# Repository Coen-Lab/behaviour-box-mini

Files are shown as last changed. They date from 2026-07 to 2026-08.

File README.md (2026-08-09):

# Behaviour Box
A deliberately simple, open-source box for recording mouse locomotion, built as a first step
towards scalable behavioural phenotyping. About **£1095** a box, six printed parts, half an hour to
assemble.

<p align="center">
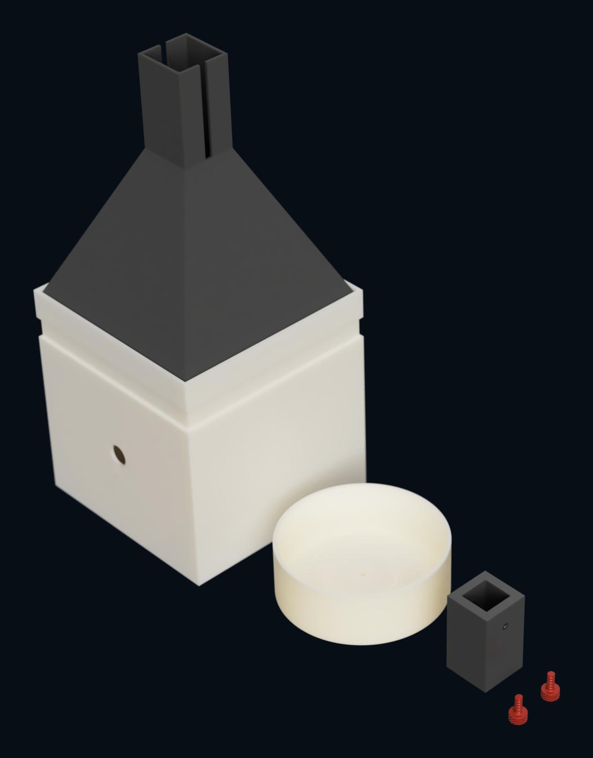
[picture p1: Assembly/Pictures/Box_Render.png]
Render of the six printed parts: box body with the lid fitted, running wheel, camera holder and two screws

</p>

## Overview

Every part is either printed or bought off the shelf, nothing needs machining, and the printed
parts need no supports. Simplicity is the point: a box that is quick to replicate, cheap enough to
run in parallel, and hard to set up wrongly.

The box pairs video capture with rotary-encoder wheel tracking, using Harp for synchronised
timestamping and Bonsai for control and acquisition. The aim is to pre-screen animals before
downstream experiments, so behavioural differences show up early — improving experimental
efficiency and reducing the number of animals needed later.

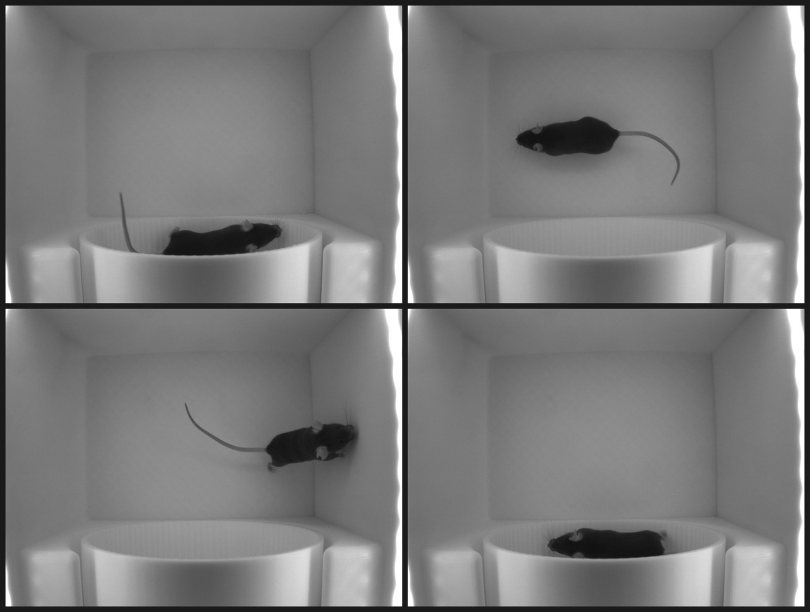
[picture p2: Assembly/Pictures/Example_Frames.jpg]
Four frames from one recording: a black mouse in the arena and on the running wheel, lit by the infrared strip


*Four frames from a single session. The wheel is against the far wall; the mouse is tracked by
centroid in both the arena and the wheel, under 850 nm light it cannot see.*

## What you get

- **Video** — continuous capture at 50 Hz for observation and offline analysis
- **Wheel locomotion** — cumulative running distance from a 1024 ppr encoder, sampled per frame
- **One clock** — the Harp board triggers the camera and timestamps the encoder, so the two streams
  share a time base rather than being aligned afterwards

## Bill of materials

| # | Part | Qty | Supplier | Cost (£) | Notes |
|---|---|-----|---|---|---|
| 1 | [PLA filament](https://uk.store.bambulab.com/products/pla-basic-filament) | 2 | Bambu Lab | 36 | 18 each |
| 2 | [FLIR Blackfly S camera](https://www.digikey.co.uk/en/products/detail/flir-integrated-imaging-solutions-inc/BFS-U3-16S2M-CS/16528335) | 1 | DigiKey | 277 | BFS-U3-16S2M-CS |
| 3 | [Rotary encoder](https://www.aliexpress.com/item/1005005665235932.html) | 1 | AliExpress | 18 | **1024 ppr** version, see notes |
| 4 | [Harp Behaviour Board](https://open-ephys.org/harp/oeps-1216) | 1 | Open Ephys | 415 | Listed at €510 |
| 5 | [Locking USB 3.0 Micro-B cable](https://www.amazon.co.uk/dp/B0BYDYKB75) | 1 | Amazon | 18 | 5 m, straight connector |
| 6 | [GPIO cable](https://www.digikey.co.uk/en/products/detail/flir-integrated-imaging-solutions-inc/ACC-01-3010/16528421) | 1 | DigiKey | 33 | Camera trigger. FLIR ACC-01-3010, Hirose HR10 6-pin, 4.5 m |
| 7 | [Varifocal lens, 2.8-12 mm, CS mount](https://www.aliexpress.com/item/1005006136279769.html) | 1 | AliExpress | 12.49 | Manual zoom and focus, no IR filter |
| 8 | [IR LED strip, 850 nm, 12 V](https://www.aliexpress.com/item/1005009046927133.html) | 2 m | AliExpress | 26 | Cut to length. Three walls need about 0.6 m |
| 9 | [Mini PC, e.g. GEEKOM Air12](https://www.amazon.co.uk/dp/B0CPLNDHZ5) | 1 | Amazon | 240 | Meets the minimum specification below |
| 10 | [M3 hex screw set, 6-14 mm](https://www.aliexpress.com/item/1005008068815080.html) | 1 | AliExpress | 9 | May be optional, see notes |
| 11 | [RJ45 breakout](https://www.aliexpress.com/item/1005009050450182.html) | 1 | AliExpress | 2 | Gets the encoder wires into Port 2 |
| 12 | [Screw terminal blocks, 5-way](https://www.aliexpress.com/item/1005007993530438.html) | 1 | AliExpress | 6.25 | Pack of 10. One terminates the encoder |
| 13 | [12 V power supply](https://www.aliexpress.com/item/4000056698173.html) | 1 | AliExpress | 2.45 | For the IR LED strip |

Approximate total: £1095

**Notes**

- **Encoder resolution** — row 3 is sold in several resolutions off the same listing, and they are
  indistinguishable in the product photographs. Choose **1024 ppr**: the workflow ships with
  `CountsPerRev` set to 4096, which is 1024 quadrature-decoded x4. Fit a different resolution
  without changing that value and `WheelDistance` is wrong in every recording, with nothing in the
  data to say so. See [Software](Software/).
- **Rotary encoder alternative** — [Omron E6B2-CWZ6C 360P/R 0.5M](https://uk.rs-online.com/web/p/motion-control-sensors/2158863),
  RS stock 215-8863, £216.14 exc VAT. Same NPN open-collector output and 6 mm shaft, but 360 ppr
  rather than 1024, and about twelve times the price. Worth it only if you need a warranted part.
  It needs `CountsPerRev` changed to 1440.
- **Screws** — Omron encoders ship with an E69-2 bracket and three M3 x 10 Phillips screws, which may
  cover the encoder mount on their own. The assembly guide calls for three M3 x 8 mm hex screws and a
  2 mm Allen key, so check what arrives before ordering row 10.

### Computer minimum specification

One machine per box runs Bonsai and writes the video. The GEEKOM Air12 in row 9 is the cheapest
unit we have found that clears the bar, so its specification is the floor:

| | Minimum |
|---|---|
| CPU | 4-core x86, Intel N-series or PT7505 class |
| RAM | 16 GB |
| Storage | 512 GB NVMe SSD |
| USB | One USB 3.2 Gen 1 Type-A port dedicated to the camera |
| OS | Windows 11, for Bonsai and the Spinnaker SDK |

Two things to watch:

- **No PCIe slot** on a mini PC, so the camera runs from a built-in port rather than an expansion card.
- **Storage** — compressed video runs at roughly 4-16 GB per hour, so 512 GB holds days rather than
  weeks. Uncompressed it would fill in under two hours, at the shipped 1440 x 1080 and 50 Hz. Binning
  2 quarters all of these figures, at half the resolution in each direction.

## Build guide

Four steps, a couple of days of printing and half an hour of assembly.

| Step | What it involves | Guide |
|---|---|---|
| 1. Print | Six parts from five STLs in [`Assembly/Parts`](Assembly/Parts/): arena, lid, camera holder, wheel, and the thumb screw twice. 15% infill, no supports, three plates on a standard Bambu Lab printer or equivalent. | [Assembly](Assembly/) |
| 2. Assemble | Mount the encoder, fit the wheel to its D-shaft, clamp the camera in its holder with the lens, and line three walls with the IR strip. 20-30 minutes. | [Assembly](Assembly/) |
| 3. Wire | Camera to computer over locking USB, GPIO trigger and encoder to the Harp board. | [Wiring](Assembly/Wiring.md) |
| 4. Software | Install the Spinnaker SDK, run `Setup.cmd`, open the workflow. | [Software](Software/) |

### Installing the software

Order matters: Bonsai cannot see the camera without the Spinnaker driver already in place.

1. **Spinnaker SDK 4.2.0.83** — download from
   [Teledyne Vision Solutions](https://www.teledynevisionsolutions.com/support/support-center/software-firmware-downloads/iis/spinnaker-sdk-download/spinnaker-sdk--download-files/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).
   The version must match exactly; the download page defaults to the latest, so choose deliberately.
   An account is required, so this step cannot be scripted.
2. **Bonsai** — run `Software\Setup.cmd`. It downloads Bonsai and
   restores every package from `Bonsai.config`, and warns if Spinnaker is missing or the wrong
   version. Nothing else needs installing by hand.
3. **Open the workflow** — start Bonsai, then **File → Open** →
   `Behaviour_Box.bonsai`. Do not launch the workflow file directly: this project relies on
   compatibility patches.

Full detail, including camera settings, is in [Software](Software/).

## How to run the workflow

Configure the camera and experiment settings first — see [Software](Software/). Then:

1. Clean the box with **70% ethanol** or another disinfectant, and wipe it completely dry.

2. Connect the hardware, with the box still empty:
   - 12 V power supply to the Harp Behaviour Board
   - Rotary encoder to the Harp Behaviour Board (**Port 2**)
   - IR LED strip power supply
   - Camera USB cable to the computer
   - Camera GPIO trigger cable to the Harp Behaviour Board

3. Open the Bonsai workflow and check the **live camera preview** is updating.

4. Place the mouse in the box.

5. Fit the lid with the camera attached.

6. Minimise external light — turn the room lights off, or cover the box with black fabric (**recommended**).

7. Set the save directory, camera serial number, subject ID, session ID and trial length, then click
   **Start**.

8. Recording stops automatically at the trial length, saving a video and a CSV of the behavioural data.

9. Return the mouse to its home cage.

10. Clean the box before the next recording, checking the corners carefully — faeces are easy to miss.

## Troubleshooting

- **No live camera preview** — check the locking USB 3.0 cable is connected, the correct Spinnaker
  SDK version is installed, and the camera serial number matches the connected device.
- **Rotary encoder not responding** — check the RJ45 connection to the Harp Behaviour Board and that
  the encoder is on the correct input pins.
- **Preview or CSV window missing** — reopen them manually, as below.

### Reopening the camera preview

1. Right-click the **Logging** node and select **Show Default Editor...**
2. In the editor window, right-click the **LogVideo** node and select **Show Default Editor...**
3. Right-click the **VideoWriter** node and select:
   - **Show Visualizer**
   - **Bonsai.Vision.Design.IplImageVisualizer**

### Reopening the CSV output

1. Right-click the **CsvWriter** node.
2. Select:
   - **Show Visualizer**
   - **Bonsai.Design.ObjectTextVisualizer**

> **Tip**
>
> Do not close these visualizer windows by hand. Bonsai closes them when the workflow stops, and
> reopens them on the next run.

## License

Released under the [MIT License](LICENSE), which covers the printed design as well as the workflow
and the documentation.

The five UclOpen packages in `local_packages/` are redistributed under the BSD 3-Clause License, and
everything `Setup.cmd` downloads stays under its own terms. See
[THIRD-PARTY-NOTICES.md](THIRD-PARTY-NOTICES.md).

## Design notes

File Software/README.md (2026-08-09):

# Software

Two components:

- **Spinnaker SDK (SpinView)** — camera driver and configuration
- **Bonsai** — acquisition, encoder recording, trigger control and data saving

Install them in that order: Bonsai cannot see the camera without the Spinnaker driver.

---

## Spinnaker SDK (SpinView)

Spinnaker is Teledyne FLIR's official package. It provides the camera driver and lets you configure
image size, exposure time, gain, frame rate and trigger mode.

Download it from
[Teledyne Vision Solutions](https://www.teledynevisionsolutions.com/support/support-center/software-firmware-downloads/iis/spinnaker-sdk-download/spinnaker-sdk--download-files/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).
An account is needed, so this step cannot be scripted and must be done by hand.

> **Important**
>
> Bonsai works only with Spinnaker SDK **4.2.0.83**. Pick the version deliberately: the download page
> defaults to the latest.
>
> This is upstream's requirement, not a local quirk. `Bonsai.Spinnaker 0.9.1` states it in its package
> description and ships a matching `SpinnakerNET_v140.dll` at exactly 4.2.0.83. The package provides
> the managed wrapper while the SDK provides the native runtime, and the two are version-locked, so a
> mismatch fails at interop and shows up as the camera simply not appearing.

---

## Bonsai

Run [`Setup.cmd`](Setup.cmd) once. It downloads Bonsai and restores
the packages listed in `Bonsai.config` from nuget.org and `local_packages/`, so nothing else needs
installing by hand.

Then, because of compatibility patches in this project, open the workflow manually rather than
launching it directly:

1. Open **Bonsai**.
2. Select **File → Open**.
3. Open **`Behaviour_Box.bonsai`**.

With the workflow loaded, click the blank workspace to bring up the experiment settings in the
**Properties** panel on the right. Set before each recording:

- Save directory
- 8-digit camera serial number
- Session ID
- Subject ID
- Trial length (minutes)

The same panel also carries the settings you change rarely rather than per recording: `PortName`,
`ExposureTime`, `Gain`, `Binning`, `TrackingThreshold`, `CountsPerRev` and `WheelDiameterMm`. None
of them require opening a group.

Recording stops automatically at the trial length, saving a **CSV** of behavioural data and a
**video**.

### Serial port

One thing is set once per machine rather than per recording. The Harp Behaviour Board appears as a
COM port, and the workflow ships pointing at **COM3**, which will be wrong on most computers. Find
the board in Device Manager under **Ports (COM & LPT)**, then set **PortName** in the same
**Properties** panel.

Get this wrong and the workflow fails on startup without saying why.

### Data output

Each recording gets its own folder, built from the settings above:

```
<save directory>\sub-<SubjectId>\ses-<SessionId>_date-<yyyy-MM-ddTHH-mm-ss>
```

The date is the UTC time at which the workflow started, so a late-evening session in British
Summer Time files under the following day. The folder holds `LogData.csv` and
`VideoData_Camera.avi`, the video written as MPEG-4 Part 2 in an AVI container.

The CSV has one row per camera frame, with a header:

| Column | Meaning |
|---|---|
| `Seconds` | Harp clock time of the frame trigger, in seconds |
| `Timestamp` | Camera chunk timestamp |
| `FrameID` | Camera frame counter |
| `ExposureTime` | Exposure of that frame, from the camera chunk |
| `MouseLocation.X` | Mouse centroid, pixels from the left edge of the image |
| `MouseLocation.Y` | Mouse centroid, pixels from the top edge of the image |
| `WheelDistance` | Cumulative distance run since the recording started, in cm |

The centroid is a `Point2f`, which Bonsai's CsvWriter splits into the two dotted columns above
rather than one combined field, so the file has seven columns. The origin is the top-left pixel and
Y increases downwards, following OpenCV.

`MouseLocation.X` and `MouseLocation.Y` are `NaN` on any frame where tracking found nothing. The
threshold segments pixels darker than 35, so an empty box gives `NaN` on every row, which is the
correct answer rather than a fault. Occasional `NaN` mid-session means the animal was momentarily
lost; a session that is entirely `NaN` with an animal present means the threshold needs raising for
the current lighting.

`Seconds` is the Harp board's own record of when it fired the trigger, matched to the frame by
arrival order rather than by any shared identifier. That holds as long as every trigger produces a
frame. If one ever does not, each frame after it takes the timestamp of the frame before, and
nothing in the file announces it. To check a session, compare the camera's own `Timestamp` against
`Seconds`: the offset between the two clocks should be flat, and a step of one frame period means
the pairing has slipped.

Expect the **first row to be wrong** and discard it. Logging starts against a camera that is already
being triggered, so the first frame is paired with a trigger event that arrived before it, and its
`Seconds` can be most of a second early. `FrameID` stays contiguous across it, confirming no frame
was lost. From the second row on, the offset locks and stays flat.

Acquisition constants, all set in the workflow:

| | Value |
|---|---|
| Frame rate | 50 Hz, camera hardware-triggered by the Harp board |
| Exposure | 10 ms |
| Gain | 5 dB |
| Binning | 1, so the full 1440 x 1080 sensor is recorded |
| Encoder counts per revolution | 4096 (1024 ppr, quadrature decoded x4) |
| Wheel diameter | 150 mm, so a circumference of 47.12 cm |
| Distance per encoder count | 0.0115 cm |

`WheelDistance` accumulates the per-sample encoder difference, with 16-bit counter wraparound
corrected, so it increases monotonically while the animal runs forwards and is not reset within a
session. Change `CountsPerRev` or `WheelDiameterMm` in the top-level **Properties** panel if you use
a different encoder or wheel, or the distances will be silently wrong.

The board is put in **Position** mode, so the encoder register reports an absolute count that the
workflow differences, unwraps and re-accumulates. UclOpen's own `RunningWheel` uses **Displacement**
mode instead, and that is deliberately not copied here: it reports differences already, so the same
chain would difference them twice and the distances would be meaningless.

---

## Camera settings

The workflow ships with recommended settings and should not need changing. If it does:

### Exposure time, gain and binning

Click the blank workspace at the top level. `ExposureTime`, `Gain` and `Binning` sit in the same
**Properties** panel as the per-recording settings, so there is no need to open the `metadata` group.

The order to tune them in is exposure first, then gain, then binning:

- **Exposure** buys image quality for free, so make it as long as the frame period allows. At 50 Hz
  a frame lasts 20 ms, and the shipped 10 ms leaves half the period spare, so this is the first
  thing to raise if the image is too dark. Going over the frame period does not slow the camera down
  gracefully: it drops triggers, and because frames are paired with trigger events in order, a
  dropped one shifts every timestamp after it.
- **Gain** amplifies noise along with signal, so keep it as low as the image allows. Reach for it
  only once exposure is maxed out and the picture is still too dark, and prefer adding IR
  illumination instead.
- **Binning** is the file-size control. It sums neighbouring pixels, so it brightens the image and
  cuts noise, at the cost of resolution. The box ships at binning 1, recording the full 1440 x 1080
  sensor. Binning 2 gives 720 x 540, quarters the data rate and brightens the image about fourfold,
  which is worth having if storage or the encoder become the limit.

### A cropped image

The workflow sets binning but not the region of interest, because `TriggeredSpinnaker` does not
expose one. `OffsetX`, `OffsetY`, `Width` and `Height` are therefore whatever is stored on the
camera, and Bonsai accepts them. A camera left with a small region records a cropped frame, and the
CSV looks identical either way.

The trap is that changing binning in SpinView does not re-expand the region. It stays at its old
pixel values, so the image crops rather than rescaling. To reset it, with Bonsai closed:

1. Set `OffsetX` and `OffsetY` to 0. The offsets must come down before the size can go up.
2. Set `Width` and `Height` to their maxima. At binning 1 that is 1440 x 1080.

To make it survive a power cycle, save it to the camera: set `UserSetSelector` to UserSet1, execute
`UserSetSave`, then set `UserSetDefault` to UserSet1. Otherwise the camera reverts to its stored
default whenever it loses power.

### Frame rate

The camera is hardware-triggered, so its frame rate is set by the Harp board rather than by the
camera. Changing it means changing three things together, or the recordings go wrong quietly:

1. **Trigger0Frequency** on the `CameraTriggerController` node, inside **metadata** then
   **BehaviorBoards**. This is the one that actually sets the rate.
2. The **frames-per-second multiplier** in the **logging** group, which turns the trial length in
   minutes into a frame count. If it disagrees with the trigger, recordings stop at the wrong
   length.
3. **FrameRate** on the `VideoWriter` node, inside **logging** then **LogVideo**. This only labels
   the AVI, but if it is wrong the video plays back at the wrong speed.

Check the exposure still fits inside the new frame period.

## Mouse centroid tracking

Position is estimated by **centroid tracking**. Compared with pose estimation or segmentation it is
computationally light, robust, and accurate enough for locomotion, which suits a standardised
screening platform.

The centroid is in pixels, and nothing in the recording converts it to distance. The arena floor is
a 200 mm square, which gets you an approximate scale, but for anything quantitative calibrate your
own box: put a ruler or a printed grid on the floor, record a frame, and measure the millimetres per
pixel. The lens is a varifocal focused by hand, so the scale belongs to your box and changes the
moment anyone touches the zoom ring.

Nothing is classified online: if you need to know whether the animal was on the wheel or in the
arena, test the logged coordinates against a wheel region offline. Doing it after the fact means one
region definition applied identically to every session, rather than one drawn by hand per rig.

> **Note**
>
> The hardware and default parameters are optimised for **black mice**. For **white or light-coloured
> mice**, either:
>
> - Print the box in a darker colour to increase contrast, or
> - Adjust `TrackingThreshold` in the top-level **Properties** panel. It ships at 35 and segments
>   pixels *darker* than that value, so a light animal on a light floor needs the box inverted in
>   colour rather than the threshold nudged.

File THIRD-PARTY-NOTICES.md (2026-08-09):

# Third-party notices

Everything in this repository is covered by the [MIT License](LICENSE) except the components listed
below, which are redistributed under their own terms.

## UclOpen packages

`Software/Behaviour_Box/local_packages/` contains five NuGet packages, redistributed as
binaries because they are not published on nuget.org and the workflow will not restore without them:

- `UclOpen.Core.0.0.0-sandbox`
- `UclOpen.Devices.0.0.0-sandbox`
- `UclOpen.Logging.0.0.0-sandbox`
- `UclOpen.Video.0.0.0-sandbox`
- `UclOpen.Vision.0.0.0-sandbox`

They come from [ucl-open/ucl-open](https://github.com/ucl-open/ucl-open) at commit
`27892d3ee53b8297eeede92571668fed8c425248`, and each carries the licence text below in its own
`LICENSE` file.

```
BSD 3-Clause License

Copyright 2026 (c) University College London and Contributors

Redistribution and use in source and binary forms, with or without
modification, are permitted provided that the following conditions are met:

1. Redistributions of source code must retain the above copyright notice, this
   list of conditions and the following disclaimer.

2. Redistributions in binary form must reproduce the above copyright notice,
   this list of conditions and the following disclaimer in the documentation
   and/or other materials provided with the distribution.

3. Neither the name of the copyright holder nor the names of its
   contributors may be used to endorse or promote products derived from
   this software without specific prior written permission.

THIS SOFTWARE IS PROVIDED BY THE COPYRIGHT HOLDERS AND CONTRIBUTORS "AS IS"
AND ANY EXPRESS OR IMPLIED WARRANTIES, INCLUDING, BUT NOT LIMITED TO, THE
IMPLIED WARRANTIES OF MERCHANTABILITY AND FITNESS FOR A PARTICULAR PURPOSE ARE
DISCLAIMED. IN NO EVENT SHALL THE COPYRIGHT HOLDER OR CONTRIBUTORS BE LIABLE
FOR ANY DIRECT, INDIRECT, INCIDENTAL, SPECIAL, EXEMPLARY, OR CONSEQUENTIAL
DAMAGES (INCLUDING, BUT NOT LIMITED TO, PROCUREMENT OF SUBSTITUTE GOODS OR
SERVICES; LOSS OF USE, DATA, OR PROFITS; OR BUSINESS INTERRUPTION) HOWEVER
CAUSED AND ON ANY THEORY OF LIABILITY, WHETHER IN CONTRACT, STRICT LIABILITY,
OR TORT (INCLUDING NEGLIGENCE OR OTHERWISE) ARISING IN ANY WAY OUT OF THE USE
OF THIS SOFTWARE, EVEN IF ADVISED OF THE POSSIBILITY OF SUCH DAMAGE.
```

## Not redistributed here

`Software/Setup.cmd` downloads Bonsai and restores the packages listed in `Bonsai.config` from
nuget.org at install time. None of those are stored in this repository, and each remains under its
own licence. Bonsai itself is MIT, copyright the Bonsai Foundation CIC and Contributors.

The Spinnaker SDK is installed by hand from Teledyne and is not redistributed in any form.

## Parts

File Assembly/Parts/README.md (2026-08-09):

# Printed parts

One STL per unique component. Six printed parts in total, five unique geometries: the thumb screw
is printed twice.

| File | Print | What it is |
| --- | --- | --- |
| `Arena.stl` | 1 | Box body, 207 x 207 x 220 mm |
| `LidAndSpacer.stl` | 1 | Tapered tower: closes the box and sets camera height, 199 x 199 x 240 mm |
| `CamHolder.stl` | 1 | Clamps the camera between body and lens, 46 x 46 x 80 mm |
| `Wheel.stl` | 1 | Running wheel, 157 mm diameter |
| `ThumbScrew.stl` | 2 | Both screws are the same part, 16 x 16 x 25 mm |

Exported from `Complete_Package` in Fusion. The meshes carry their assembly coordinates rather than
being centred on the origin, so parts land away from the plate when first loaded. Any slicer will
drop them to the bed and place them; nothing about the geometry needs changing.

For print settings and the build order see [../README.md](../README.md).

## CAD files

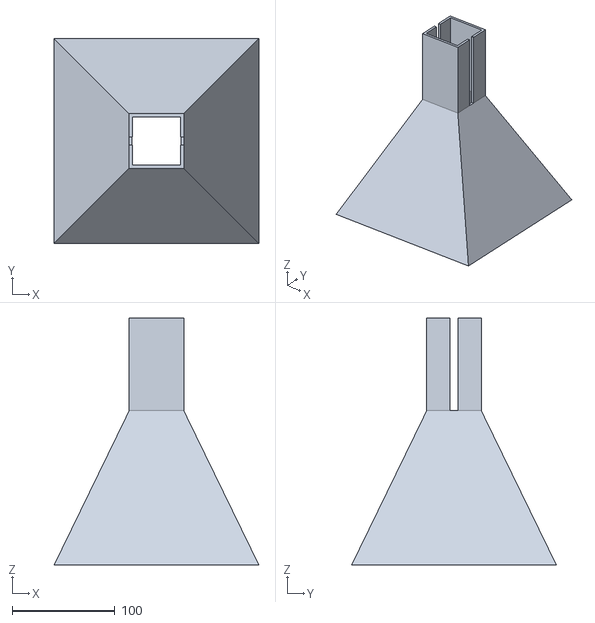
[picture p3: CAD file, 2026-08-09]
Assembly/Parts/LidAndSpacer.stl
199.0 x 199.0 x 240.0

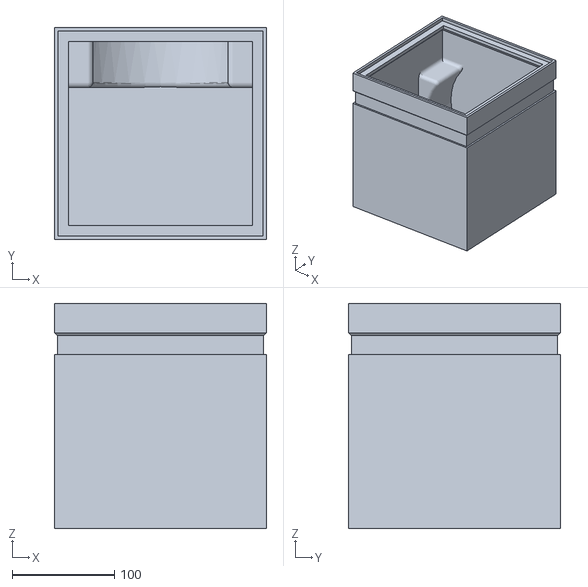
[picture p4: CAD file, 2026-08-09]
Assembly/Parts/Arena.stl
207.0 x 207.0 x 220.0

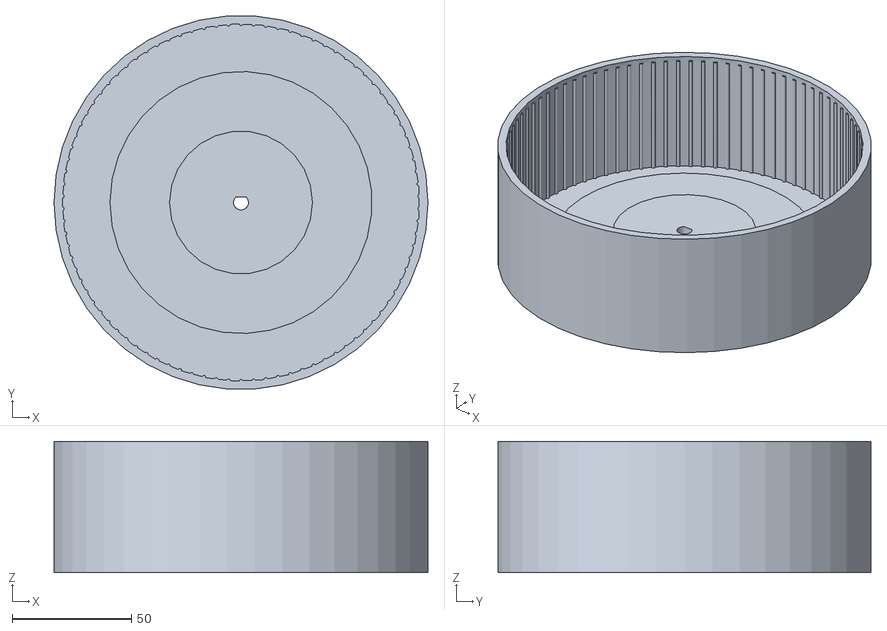
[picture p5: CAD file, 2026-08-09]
Assembly/Parts/Wheel.stl
157.0 x 156.6 x 55.0

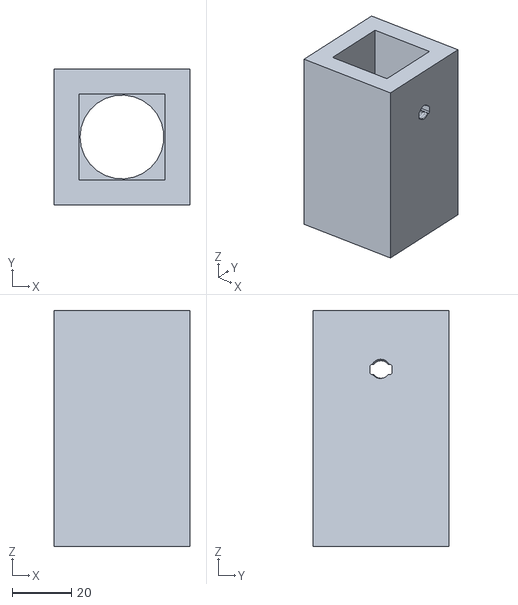
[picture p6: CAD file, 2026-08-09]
Assembly/Parts/CamHolder.stl
46.0 x 46.0 x 80.0

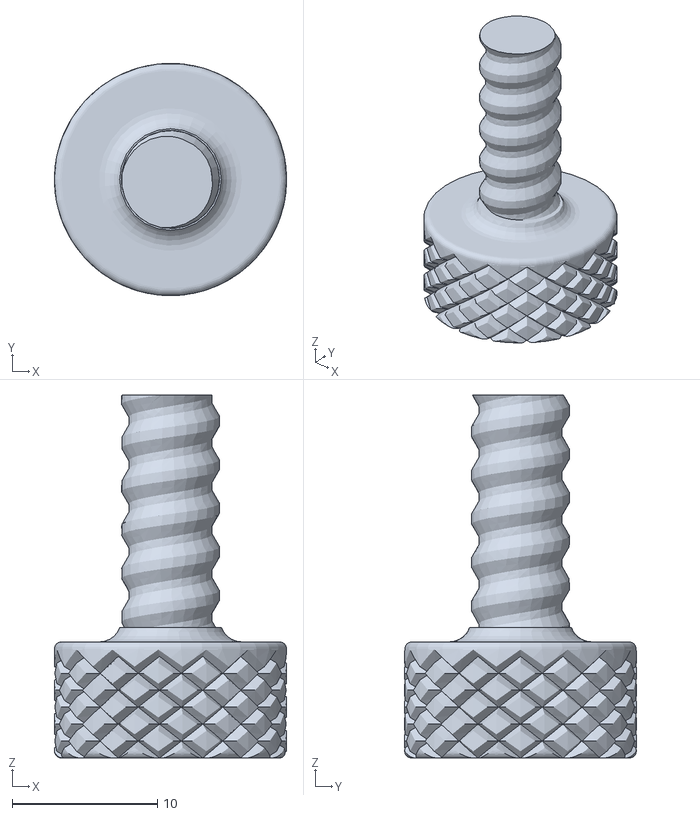
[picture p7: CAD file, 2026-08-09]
Assembly/Parts/ThumbScrew.stl
16.0 x 16.0 x 25.0

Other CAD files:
Assembly/Behaviour_Box_Complete.step
Assembly/Behaviour_Box_Complete.stl

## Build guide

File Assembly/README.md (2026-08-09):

# Assembly

Printing, assembling and wiring the box. For the parts list and prices see the
[Bill of materials](../README.md#bill-of-materials); for wiring see [Wiring](Wiring.md).

Six printed parts, from five files in [`Parts/`](Parts/):

- `Arena.stl` — the box body
- `LidAndSpacer.stl` — the tapered tower that closes the box and sets the camera height above the
  arena. It is 240 mm tall, so it doubles the assembled height to 460 mm; allow for that on the
  bench and in the printer
- `CamHolder.stl` — camera holder
- `Wheel.stl` — running wheel
- `ThumbScrew.stl` — printed twice; both screws are the same part

Everything else is bought off the shelf, as listed in the [Bill of materials](../README.md#bill-of-materials).
Assembly takes 20-30 minutes.

<p align="center">
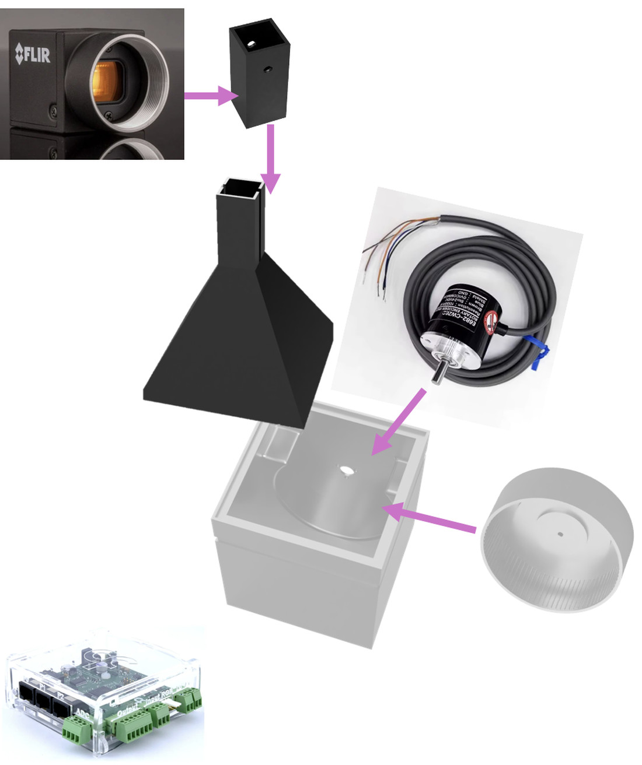
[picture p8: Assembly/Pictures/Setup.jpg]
Assembly overview: the camera slides into the camera holder, the holder into the top of the lid, the lid onto the box body; the encoder mounts through the side wall and the wheel onto its shaft; the Harp Behaviour Board sits outside
  
</p>

<p align="center"><em>How the parts go together. The Harp Behaviour Board sits outside the box; see
<a href="Wiring.md">Wiring</a>.</em></p>

## Tools required

- 2 mm Allen key, for the M3 screws
- Flat-head screwdriver

## Step 1 - Print the components

Print the five files in [`Parts/`](Parts/), taking two copies of `ThumbScrew.stl`.

| Setting | Value |
|---|---|
| Material | PLA |
| Infill | 15% |
| Supports | None needed |
| Build volume | At least 210 x 210 x 245 mm |
| Printer | Standard Bambu Lab or equivalent |

The two largest parts set the build volume: the box body is 207 mm square and 220 mm tall, and the
lid is 199 mm square and 240 mm tall. Both fit an X1 or P1 series printer, but not an A1 mini.

Each file holds one part, but the meshes keep their assembled coordinates, so they arrive spread out
and at different heights. Drop everything to the plate and arrange it yourself. They will not fit on
one plate: budget three, and closer to two or three days of printing than one.

[`Behaviour_Box_Complete.stl`](Behaviour_Box_Complete.stl) is the whole box as a single body, for
reference only — it cannot be printed. [`Behaviour_Box_Complete.step`](Behaviour_Box_Complete.step)
is the editable solid model, with each part as a separate component.

Print the box in a darker colour if you plan to record white or light-coloured mice, for contrast.

## Step 2 - Install the rotary encoder

Secure the encoder to the side wall of the box with three M3 x 8 mm screws, with the shaft facing
inwards. See [Wiring](Wiring.md) for the encoder connections.

## Step 3 - Install the running wheel

1. Turn the shaft until the flat of the D faces the matching flat inside the wheel hub.
2. Push the wheel home. It should slide on smoothly; if it needs force, the flats are not aligned.

## Step 4 - Install the camera

1. Remove the lens from the camera body.
2. Insert the camera through the camera holder from the rear.
3. Reattach the lens from the front, clamping the holder between the camera body and the lens so it
   cannot move.
4. Slide the holder into the square opening at the top of the lid and lock it with the two printed
   screws. Either screw goes in either hole.

See [Wiring](Wiring.md) for the camera power and trigger connections.

## Step 5 - Fit the infrared illumination

The 850 nm strip lights the arena for the camera without being visible to the mouse.

1. Cut about 600 mm from the 2 m reel — the interior is 200 mm square and three walls are lined.
   Cut **only on the marked cut points**, which on a 12 V strip fall every few LEDs. Cut anywhere
   else and the segment will not light.
2. Peel the backing and run the strip along **three of the four walls, leaving the wheel wall
   dark**. Three sides give even light across the floor, and keeping the strip off the wheel wall
   avoids both the encoder mount and the shadow the wheel would throw across the arena.
3. Connect the strip to its own 12 V supply, not to the Harp board.

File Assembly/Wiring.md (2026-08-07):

# Wiring

Three things connect to the system: the camera, the rotary encoder and the Harp Behaviour Board.

<p align="center">
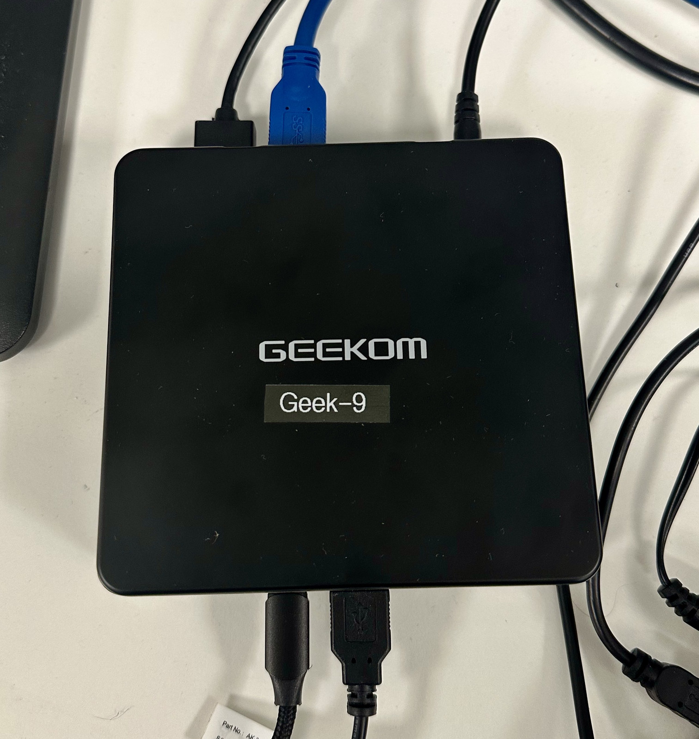
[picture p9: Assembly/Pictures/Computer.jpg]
The mini PC, with the camera USB cable and the monitor and power leads plugged in
  
</p>

---

## Camera

The camera needs two connections:

- **Locking USB 3.0 Micro-B cable** — straight to the computer, for image acquisition.
- **GPIO trigger cable** — to the **Output** port of the Harp Behaviour Board, for hardware triggering.

For the **FLIR Blackfly S (BFS-U3-16S2M-CS)** in the bill of materials:

| Camera wire | Connect to |
|---|---|
| Blue (Opto GND) | GND |
| Black (Opto In) | Trigger |

<p align="center">
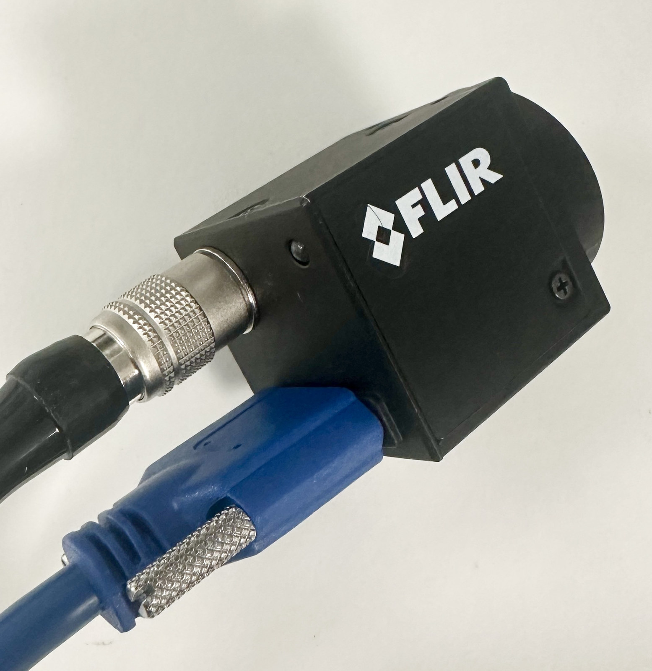
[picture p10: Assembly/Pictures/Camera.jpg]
Camera connections
  
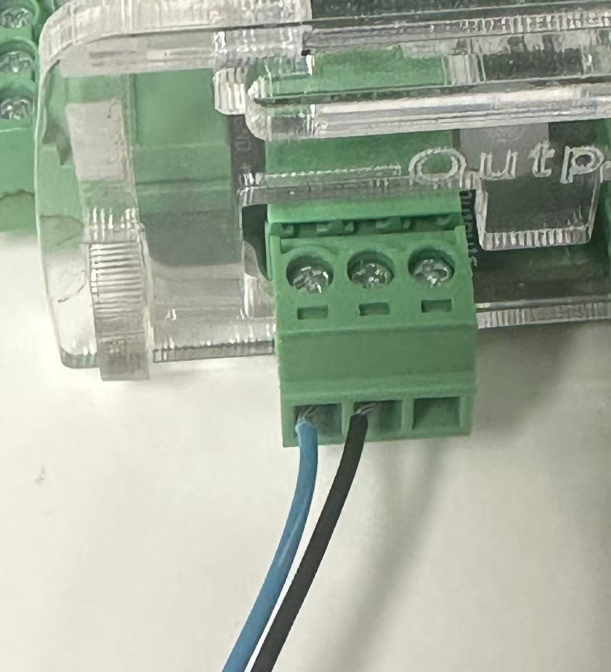
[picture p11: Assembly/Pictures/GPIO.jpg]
GPIO trigger wiring
  
</p>

Camera configuration is covered in [Software](../Software/).

---

## Rotary encoder

The encoder connects to the Harp Behaviour Board over RJ45, on **Port 2**. This is not a preference:
Port 2 is the only one of the three ports wired to the board's quadrature counter, and the workflow
enables it by name. To simplify assembly and replacement, terminate the encoder wires in an **8-way
screw terminal block** first.

The encoder has five wires, four of which are used:

| Encoder wire | Harp pin |
|---|---|
| Black (Channel A) | DI (Input A) |
| White (Channel B) | DIO (Input B) |
| Orange — *not used* | Pin 3 |
| Brown (+5 V) | Pin 4 |
| Blue (GND) | Pin 5 |

The bare braid is the cable shield, not one of the five wires.

<p align="center">
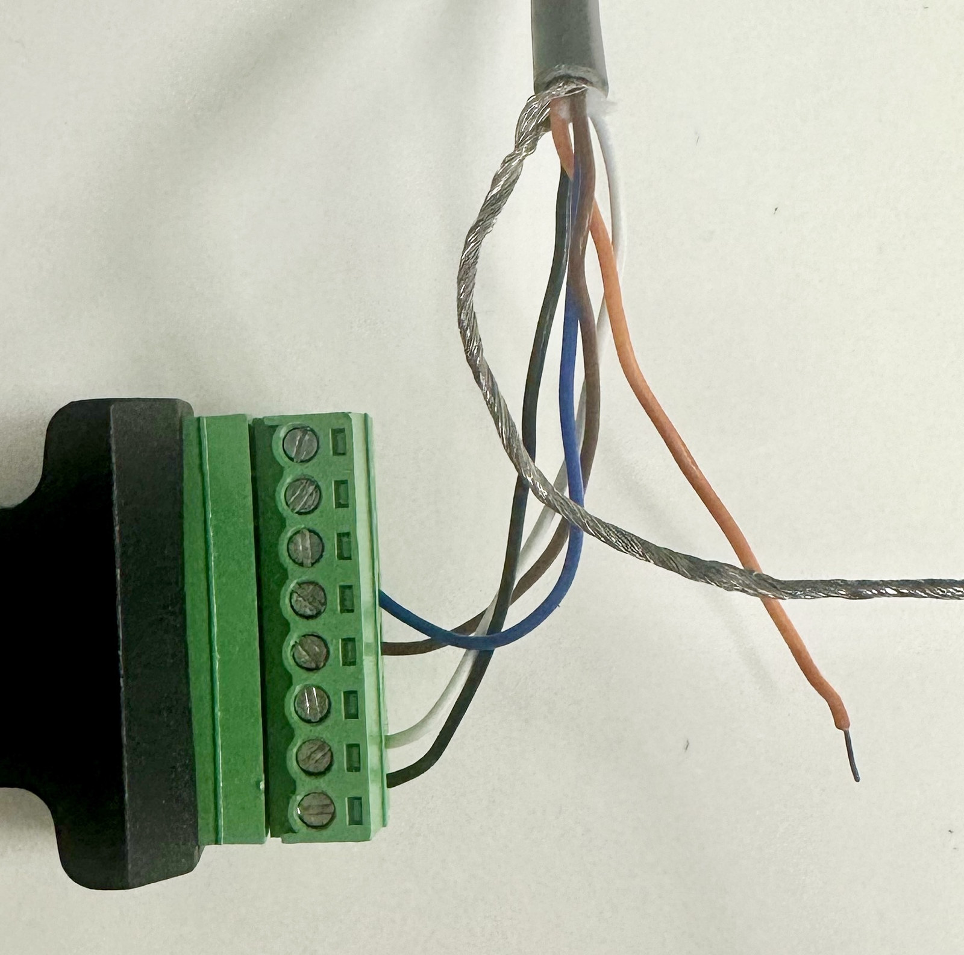
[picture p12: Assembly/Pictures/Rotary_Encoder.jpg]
Rotary encoder wiring
  
</p>

---

## Harp Behaviour Board

The board is the central interface between camera, encoder and computer. It needs:

- USB to the computer
- 12 V DC power in
- GPIO output to the camera trigger cable
- RJ45 to the rotary encoder (**Port 2**, the only port with a quadrature counter)

<p align="center">
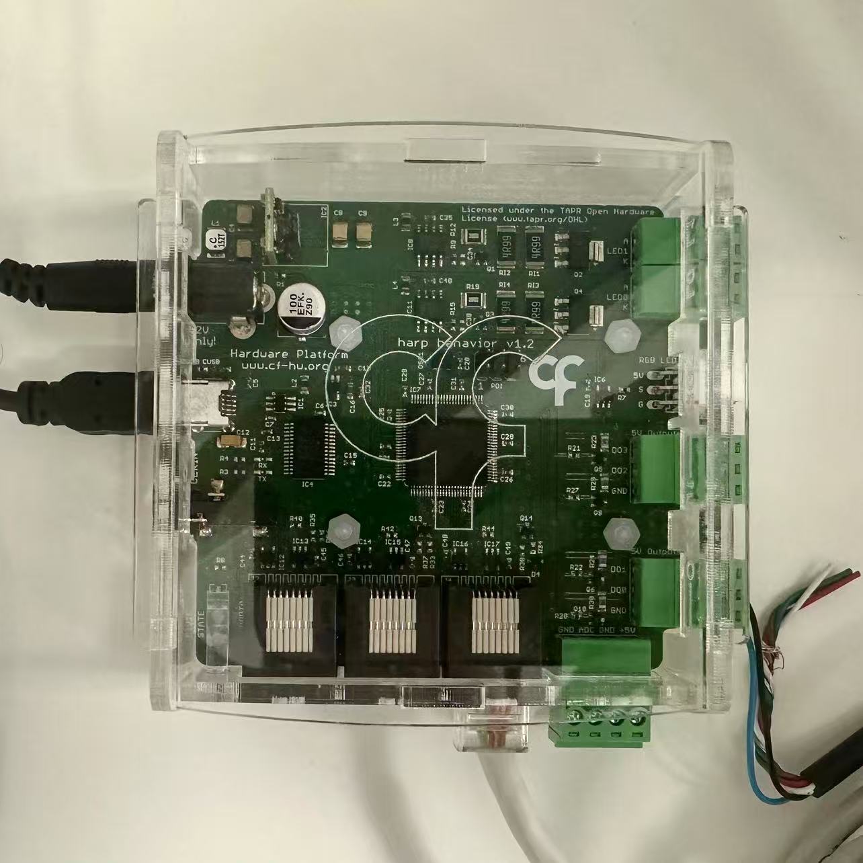
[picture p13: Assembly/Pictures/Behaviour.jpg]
Harp Behaviour Board connections
  
</p>

With the hardware connected, go to [Software](../Software/) for device configuration and
acquisition.

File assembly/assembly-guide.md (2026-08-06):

# Assembly Guide

The box is four 3D-printed PLA parts:

- Behaviour box body
- Lid
- Camera holder
- Running wheel

Everything else is bought off the shelf, as listed in the [Bill of Materials](../README.md#bill-of-materials).
Assembly takes 20-30 minutes.

<p align="center">
  Assembled behaviour box
</p>

## Tools Required

- 2 mm Allen key, for the M3 screws
- Flat-head screwdriver

## Step 1 - Print the components

Print the four PLA parts. No supports are needed; they print straight off a standard Bambu Lab
printer or equivalent, at 15% infill.

## Step 2 - Install the rotary encoder

Secure the encoder to the side wall of the box with three M3 x 8 mm screws, with the shaft facing
inwards. See [wiring](wiring.md) for the encoder connections.

## Step 3 - Install the running wheel

Slide the wheel onto the encoder shaft. The hub is designed to mate with the D-shaped shaft, so
align the flat of the shaft with the matching flat inside the hub before pushing the wheel home. It
should slide on smoothly, without excessive force.

## Step 4 - Install the camera

1. Remove the lens from the camera body.
2. Insert the camera through the camera holder from the rear.
3. Reattach the lens from the front, clamping the holder between the camera body and the lens so it
   cannot move.

See [wiring](wiring.md) for the camera power and trigger connections.

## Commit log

2026-07-24 Revise assembly guide and update step numbering
    Updated assembly guide to reflect changes in step numbering and removed unnecessary text.
2026-07-24 Update build guide for printing and assembly
    Consolidate print and assembly steps in the build guide.
2026-07-27 Improve image alignment in wiring.md
    Updated image formatting for better alignment in wiring documentation.
2026-07-27 Revise wiring.md with updated connections and images
    Updated wiring instructions and added images for clarity.
2026-07-27 Fix formatting issues in wiring documentation
2026-07-27 Update assembly guide with material and tool details
    Added note about printed parts being designed for PLA and updated tools required section.
2026-07-27 Adjust image width in assembly guide
    Increased the image width in the assembly guide.
2026-08-06 Add lens, IR strip, computer and screws to the BOM
    Link the rows that map to parts already in RegularOrders.xlsx and
    AliExpressOrders.xlsx, so suppliers and prices match what the lab pays.
    The GPIO cable is the FLIR ACC-01-3010 and the camera comes from Digikey
    at the price we last paid.
    Add four rows the BOM was missing: the CS-mount varifocal lens, the
    850 nm IR strip the run instructions already assume, the mini PC, and the
    M3 screw set. Give the computer a minimum specification, since the
    workflow depends on one but never said what it needs.
    Add a collage of example frames and an exploded render of the printed
    parts.
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2026-08-06 Use the exploded render as the header image
    Replaces the hosted model screenshot. The render lives in the repo rather
    than in GitHub attachment storage, and it shows every printed part rather
    than the assembled box alone. Drops the duplicate copy from the build
    guide.
2026-08-06 Rebuild the header render from the green-screen export
    Keying against grey was never going to work: the box's shaded left face
    sits 13 counts from the background, so removing background-coloured edge
    pixels also removed part of the model, leaving a ragged silhouette.
    Green shares no ground with the model's white, black and red, so the
    matte comes from green dominance instead of colour distance. No opaque
    green-tinted pixels survive, and no erosion is needed.
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2026-08-06 Use the solid-background render and tighten the README
    Swap in the render exported against a solid dark background, replacing
    the keyed transparent version.
    Convert the features list to bullets, cut repetition from the overview
    and run-through, and lead on the design being simple to build. Fix the
    software link, which pointed at assembly/ rather than Softwares/.
    Note what the M3 screws are for: the assembly guide specifies three
    M3 x 8 mm to mount the rotary encoder.
2026-08-06 Note the encoder ships with its own screws; no supports when printing
    Omron E6B2-C encoders include an E69-2 bracket and three M3 x 10 Phillips
    screws, so the separate hex set may not be needed. The assembly guide
    calls for M3 x 8 hex, a different head and length, so flag it rather than
    dropping the row.
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2026-08-06 Note the genuine Omron encoder as an alternative
    E6B2-CWZ6C 360P/R 0.5M, RS 215-8863, at £216.14 exc VAT against £18 for
    the AliExpress part. Lower resolution than the 1024 ppr specified, so it
    is a fallback for warranty rather than a like-for-like swap.
2026-08-06 Audit the docs for typos, consistency and length
    Rename Softwares/ to Software/ and update every reference.
    software.md pointed readers at a mouse_box_ucl_open folder that no longer
    exists; the workflow is in Behaviour_box_ucl_open. Fixed, and linked.
    Across all four documents: close the unbalanced <p> tags, replace
    full-width brackets with ASCII, make bare lines into bullets, settle on
    one dash style in headings, and cut repetition. Normalise the BOM's
    supplier and part names (AliExpress, DigiKey, Harp) and give the cost
    column a unit instead of the 18*2 cell.
2026-08-06 Document the Spinnaker install and the Setup.cmd step
    Setup.cmd restores Bonsai and its packages, but nothing installs the
    Spinnaker SDK, without which Bonsai cannot see the camera. The required
    version was stated but never linked, and the download page defaults to
    the latest, so say where to get it and to choose the version deliberately.
2026-08-06 Check prerequisites in Setup.ps1
    Warn when the Spinnaker SDK is missing or the wrong version, since that
    is the failure a new user is most likely to hit and it presents as the
    camera simply not appearing. Warn rather than stop: the workflow still
    opens without a camera.
    Also check local_packages/ has content, which otherwise fails later as an
    opaque NuGet error, and report where to go next when the restore finishes.
2026-08-06 Render a guide when you open assembly/ or Software/
    GitHub only auto-renders README.md, so opening either folder showed a
    bare file list rather than the guide sitting inside it. Rename each
    folder's guide to README.md and repoint the links.
    Make the build guide say what each step actually involves, with the
    print settings as a table in assembly/ rather than a sentence.
2026-08-06 Record why the Spinnaker version is pinned
    Bonsai.Spinnaker 0.9.1 states the 4.2.0.83 requirement in its own package
    description and ships a matching SpinnakerNET_v140.dll. The package is
    the managed wrapper and the SDK is the native runtime, so a mismatch
    fails at interop and looks like the camera not appearing.
2026-08-06 Update the printed parts STL
    [Behaviour_box_Mini.stl]
2026-08-06 Correct the part count and add install instructions to the README
    The STL holds six printed parts, not four: the box body, lid, camera
    holder and running wheel, plus two screws.
    Installation was a single line in a table pointing two clicks away.
    Spell out the order, since Bonsai cannot see the camera unless Spinnaker
    is installed first, and that is the failure people hit.
2026-08-06 Document what the CSV actually contains
    Columns, units and acquisition constants read out of the workflow: 50 Hz
    hardware-triggered frames, 4096 counts per revolution, a 150 mm wheel,
    and cumulative distance in cm with 16-bit wraparound corrected.
    Also correct the tracking section. It said centroid X and Y are written
    to the CSV; they are not. The centroid is used to classify each frame as
    Wheel or Arena, and only that classification is logged.
2026-08-06 Correct the CSV column meanings
    MouseLocation is the centroid X and Y; Area is the Wheel/Arena region
    name. A previous commit had these the wrong way round and claimed the
    centroid was not logged. Traced through the workflow graph: cv:Centroid
    publishes Mouse_centroid, which is Zip source 5 and maps to
    MouseLocation, while the merged Wheel/Arena strings publish the subject
    named Area, which is source 6.
2026-08-06 Drop the online Wheel/Arena classification
    Keeps the vision chain through cv:Centroid, so the centroid is still
    logged as MouseLocation. Removes the two CropPolygon nodes, the
    point-in-polygon test, the Wheel/Arena strings and the Area column, and
    takes the record Zip from six sources to five.
    This removes the polygon calibration step, which had to be redone
    whenever camera height, lens, rotation or box geometry changed and was
    silently wrong if skipped. Wheel versus arena is recoverable offline from
    the logged coordinates, with one region definition applied identically to
    every session.
    Removing nodes renumbers everything after them, so the saved visualizer
    layouts are remapped by the sam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
2026-08-06 Move Setup.cmd to Software/ and settle heading capitalisation
    Setup.cmd was three levels down inside a hidden .bonsai folder, which is
    Bonsai's own layout but hard to find for anyone following the README. The
    launcher now sits at Software/Setup.cmd and pushes into the .bonsai folder
    to run Setup.ps1, which has to stay beside Bonsai.exe.
    Headings were a mix of Title Case and sentence case, sometimes adjacent.
    Settle on sentence case throughout, keeping proper nouns. Section anchors
    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
2026-08-06 Correct the encoder port: it is Port 2, not P0
    The Harp Behaviour Board has one quadrature counter and it is on Port 2.
    Harp.Behavior's EncoderInputs enum offers only None and EncoderPort2, and the
    workflow writes EnableEncoders=EncoderPort2 and EncoderReset=EncoderPort2.
    Anyone wiring the encoder to Port 0 as the docs said would get no wheel data.
2026-08-06 Document the CSV columns and output folder from a real recording
    MouseLocation is a Point2f and Bonsai's CsvWriter splits it into
    MouseLocation.X and MouseLocation.Y, so LogData.csv has seven columns, not
    six. Verified by running the same Grayscale/Threshold/FindContours/Centroid
    chain headless through Bonsai 2.9.1 against a test image with a known blob
    centre. The header came out as
    Seconds,Timestamp,FrameID,ExposureTime,MouseLocation.X,MouseLocation.Y,WheelDistance
    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
2026-08-06 Settle the frame rate at 50 Hz
    Four numbers that have to agree did not. The Harp board triggers at 50 Hz, but
    the exposure was 33 ms, the trial-length maths multiplied minutes by 30 and the
    VideoWriter labelled the AVI 30 fps. Whichever way the rig was actually running,
    something was wrong: either every recording stopped at 0.6x the requested length
    and played back slow, or the camera was delivering ~30 frames a second against a
    50 Hz trigger event stream and every timestamp was drifting.
    50 Hz is the intended rate, so:
    * exposure 33000 -> 19000 us, the longest that fits inside a 20 ms frame
    period. This is also what UclOpen's TriggeredSpinnaker defaults to.
    * trial-length multipli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
2026-08-06 Drop the gain to 5 dB
    Gain amplifies noise with signal, and 20 dB was buying brightness that the IR
    illumination should be providing. 5 dB keeps a little headroom without visibly
    costing image quality.
    This lands on top of the exposure cut in the previous commit, so the two
    together take about an order of magnitude out of the image: 20 dB to 5 dB is
    roughly 5.6x, and 33 ms to 19 ms another 1.7x. The box will want more IR light,
    and the Threshold of 35 that picks the mouse out of the background should be
    rechecked against a real recording before the settings are trusted.
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2026-08-06 Add the three BOM parts the build silently assumed
    Following the guide end to end leaves you short of three things that were never
    listed. wiring.md tells you to terminate the encoder in a 5-way screw terminal
    block, and something has to get that into an RJ45 port, and the IR strip needs
    a 12 V supply of its own. All three are ordinary lab-sheet purchases, priced
    from what we last paid.
    Also record that the GPIO cable is 4.5 m, which matters when siting the box
    relative to the computer.
    Total goes from about 1085 to about 1095.
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2026-08-06 Document the things a second lab would have to work out alone
    Five gaps, all of them the sort that cost a day each:
    * The COM port. The workflow ships pointing at COM3 and nothing said so, so on
    any other machine it fails at startup with no clue why. Says where to change
    it now.
    * The video codec, MPEG-4 Part 2 in AVI.
    * What Seconds actually is. It is the board's record of firing the trigger,
    matched to the frame by arrival order, so a single missing frame silently
    reassigns every timestamp after it. Comparing the camera's Timestamp against
    Seconds catches it; nothing else in the file does.
    * Scale. MouseLocation is in pixels with no way to reach millimetres. Th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
2026-08-06 Restore the flow broken by the serial-port insert
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2026-08-07 Describe what the images actually show
    The three alt texts were each wrong about their own picture. Box render.png
    is not exploded: the lid is fitted to the body. Setup.jpg is a components
    slide, not the assembled box. Computer.jpg has no Harp board in it.
2026-08-07 Settle the copy-editing inconsistencies
    One 'shroud' where the part is the lid everywhere else, one Title Case
    'Bill of Materials', one 'Licence' two lines from 'License', two multiply
    signs where the rest of the docs use x, one blank line making the
    troubleshooting list the only loose list on the page, one unwrapped line.
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2026-08-07 Make the first screen answer the first question
    Price in the tagline, hero narrow enough that the Overview clears the fold.
    Features restated the Overview in bullet form and claimed two things the
    repo does not support. Replaced with the three measurements you actually
    get, one of which - the shared clock - was the strongest argument in the
    document and was buried.
    Wire the box before the mouse goes in it, not after: it was five cables
    into a closed dark box with an animal already inside. Step 7 was missing
    the camera serial number that the software guide and this page's own
    troubleshooting both require.
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2026-08-07 Say why 1024 ppr is not a preference
    The linked listing sells the same encoder in several resolutions and they
    are indistinguishable in the product photographs. Pick the wrong one and
    WheelDistance is wrong in every recording, silently, because CountsPerRev
    stays at 4096. The BOM said '1024 ppr version' and left the consequence
    in another file.
    Same reason the Omron alternative now states the value it needs: 360 ppr
    is 1440 counts, not 4096.
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2026-08-07 One name, one capitalisation convention
    The tree could not decide: Software/ capitalised but assembly/ not,
    Pictures/ capitalised inside it, wiring.md lowercase beside README.md,
    Behaviour_box_Mini.stl capitalising two words out of three, and three
    image filenames carrying spaces that every link had to write as %20.
    assembly/ -> Assembly/
    assembly/wiring.md -> Assembly/Wiring.md
    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
    [Behaviour_Box_Mini.stl]
2026-08-07 Update rotary encoder wiring instructionsTypo
    Corrected the wiring terminal block description from 5-way to 8-way.
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2026-08-09 Add the STEP export alongside the STL
    Both exported from Fusion on 9 Aug. The STL is refreshed from the current
    design and replaces the previous one; the STEP is new.
    STEP carries the solid geometry rather than a triangle mesh, so the parts
    can be opened, edited and re-meshed in any CAD package. The STL is still
    the right thing to slice from, but it is a dead end for anyone wanting to
    change a dimension.
    Both files remain a single assembled body. Per-part files that someone
    could actually print are still missing.
    [Behaviour_Box_Complete.step, Behaviour_Box_Complete.stl]
2026-08-09 Add per-component STLs so the box can actually be printed
    Assembly/Parts/ holds one STL per printed component: Arena, CamHolder,
    CamSpacer and Wheel. Until now the repo shipped only the assembled body,
    which slices as a single fused object and cannot be printed.
    Exported from Complete_Package via the Fusion Data API rather than by hand,
    so re-exporting on a design change is a scripted step rather than a
    click-through.
    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
    [Arena.stl, CamHolder.stl, CamSpacer.stl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]
2026-08-09 Add the thumb screw and a parts list
    Both thumb screws are the same part: 5714 triangles each, both 16 x 16 x 25 mm,
    differing only in Y placement (+20 vs -20) because the export carries assembly
    coordinates. One file, printed twice.
    Assembly/Parts/README.md gives the quantity for each file and notes that the
    meshes arrive in assembly coordinates rather than centred on the origin, so
    they land away from the plate until the slicer places them.
    [ThumbScrew.stl]
2026-08-09 Rename the lid part, re-export everything, and fix the docs
    CamSpacer is now LidAndSpacer, in Fusion and here. It is 199 x 199 x 240 mm,
    the second largest part in the box, and "spacer" undersold it: it both closes
    the box and sets the camera height.
    Every file re-exported from the current design so the repo matches Fusion:
    five part STLs, the complete STL, and a complete STEP that now carries the six
    components as separate products. The previous STEP predated the conversion from
    bodies to components and held a single fused solid under the old design name.
    Docs corrected. Assembly/README.md linked to Behaviour_Box_Mini.stl, which has
    not existed since the file was renamed, and still told p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
    [Behaviour_Box_Complete.step, Behaviour_Box_Complete.stl, LidAndSpacer.stl]
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
